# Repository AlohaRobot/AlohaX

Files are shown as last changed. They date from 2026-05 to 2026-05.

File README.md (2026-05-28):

AlohaX_缩小

# AlohaX Project

Dual-arm mobile robot project based on ROS2 Humble.

## Project Overview

AlohaX is a dual-arm robot system with the following features:
- **Dual-arm system**: Left and right 6-DOF arms (SOARM101)
- **Mobile base**: Dual drive wheel platform
- **Vertical lift**: Additional lift DOF (ID 11)

## Project Structure

```
alohax_ws/
├── src/
│   ├── alohax_urdf/              # URDF robot model and mesh files
│   ├── alohax_hw_bridge/         # Hardware bridge (core)
│   ├── alohax_moveit_config/     # MoveIt motion planning config
│   ├── alohax_bringup/           # Launch scripts
├── docs/                         # Project documentation
│   ├── AlohaX_Robot_Introduction.md
│   ├── AlohaX_BOM.md
│   ├── AlohaX_Assembly_Guide.md
│   ├── Serial_Port_Fix_Method.md
│   └── media/                    # Documentation images
├── examples/                     # Example programs
│   ├── debug/                    # Debug tools
│   │   ├── motors.py             # Motor control debug
│   │   ├── axis.py               # Lift axis control
│   │   ├── wheels.py             # Base control
│   │   ├── README_debug.md       # Debug tool usage guide
│   │   ├── action_scripts/       # Action scripts
│   │   │   ├── go_to_restposition.txt
│   │   │   ├── go_to_midpoint.txt
│   │   │   └── test_dance.txt
│   │   ├── test_cv.py            # Computer vision test
│   │   ├── test_mic.py           # Microphone test
│   │   ├── test_cuda.py          # CUDA test
│   │   ├── test_network.py       # Network test
│   │   ├── test_dataset.py       # Dataset test
│   │   └── test_input.py         # Input test
│   └── tele/                     # Teleoperation programs
│       ├── alohax_xbox.py        # Xbox controller
│       ├── alohax_keyboard.py    # Keyboard control
│       ├── alohax_joycon.py      # Joycon control (recommended)
│       ├── wheels_joycon.py      # Joycon base control
│       └── AlohaX_Joycon_Software_Design.md  # Joycon control detailed design
├── build/                        # Build output
├── install/                      # Install output
└── log/                          # Log output
```

## Hardware Configuration

### Motor Bus Configuration

**Bus1** (`/dev/so101_L`):
- ID 1-6: Left arm joints
- ID 7-8: Drive wheels (velocity mode)
- ID 11: Vertical lift

**Bus2** (`/dev/so101_R`):
- ID 1-6: Right arm joints

### Joint Configuration

Robot includes the following joints:

**Left arm (6 DOF)**:
- `left_arm_shoulder_pan`: Shoulder pan
- `left_arm_shoulder_lift`: Shoulder lift
- `left_arm_elbow_flex`: Elbow flex
- `left_arm_wrist_flex`: Wrist flex
- `left_arm_wrist_roll`: Wrist roll
- `left_arm_gripper`: Gripper

**Right arm (6 DOF)**:
- `right_arm_shoulder_pan`: Shoulder pan
- `right_arm_shoulder_lift`: Shoulder lift
- `right_arm_elbow_flex`: Elbow flex
- `right_arm_wrist_flex`: Wrist flex
- `right_arm_wrist_roll`: Wrist roll
- `right_arm_gripper`: Gripper

**Base**:
- `base_left_wheel`: Left drive wheel
- `base_right_wheel`: Right drive wheel

**Lift**:
- `vertical_lift`: Vertical lift DOF

## Quick Start

### Environment Requirements

- ROS2 Humble
- Python 3.10+
- Feetech servo drivers

### Build Project

```bash
cd /home/wolf/alohax_ws
colcon build --symlink-install
source install/setup.bash
```
```bash
cd /home/seeed/alohax_ws
colcon build --symlink-install
source install/setup.bash
```

### Launch Robot

#### 1. Visualize model (without hardware connection)

```bash
ros2 launch alohax_urdf display.launch.py
```

#### 2. Full launch (real hardware)

```bash
ros2 launch alohax_bringup alohax.launch.py
```

#### 3. Specify serial ports

```bash
ros2 launch alohax_bringup alohax.launch.py \
  port1:=/dev/ttyACM0 \
  port2:=/dev/ttyACM1
```

#### 4. Visualize only (without hardware)

```bash
ros2 launch alohax_bringup alohax.launch.py hardware:=false
```

#### 5. Launch parameter description

`alohax.launch.py` supports the following optional parameters:

| Parameter | Default | Description |
|---|---|---|
| `hardware` | `true` | Whether to connect real hardware |
| `gui` | `false` | Whether to start joint_state_publisher_gui |
| `moveit` | `true` | Whether to start MoveIt |
| `port1` | `/dev/so101_L` | Left serial port |
| `port2` | `/dev/so101_R` | Right serial port |
| `calib_file` | `alohax_calibration.yaml` | Calibration file path |
| `publish_hz` | `50.0` | Joint state publish rate (Hz) |
| `lift_travel_m` | `0.25` | Lift travel (meters) |
| `lift_motor_degrees_per_meter` | `144000.0` | Lift motor degrees per meter |
| `rviz` | `true` | Whether to start RViz2 |

### Launch MoveIt Motion Planning

```bash
ros2 launch alohax_moveit_config move_group.launch.py
```

## Controller Configuration

Project has the following controllers configured:
- `both_arms_controller`: Dual-arm combined control (includes vertical_lift)
- `left_arm_controller`: Left arm independent control (includes vertical_lift)
- `right_arm_controller`: Right arm independent control
- `left_gripper_controller`: Left gripper control
- `right_gripper_controller`: Right gripper control
- `joint_state_broadcaster`: Joint state broadcaster

Config file locations:
- [alohax_controllers.yaml](src/alohax_hw_bridge/config/alohax_controllers.yaml)
- [alohax_calibration.yaml](src/alohax_hw_bridge/config/alohax_calibration.yaml)

## Calibration and Tuning

### Calibration File

Calibration file is at `src/alohax_hw_bridge/config/alohax_calibration.yaml`, contains:
- `homing_offset`: Zero offset
- `range_min`: Minimum position
- `range_max`: Maximum position

### Adjust Calibration Parameters

Adjust parameters in calibration file based on actual hardware:

```yaml
left_arm_shoulder_pan:
  homing_offset: 2084
  range_min: 745
  range_max: 3424
```

## Troubleshooting

### Common Issues

**1. Hardware connection failed**

```bash
# Check serial ports
ls -l /dev/so101_L /dev/so101_R

# Check permissions
sudo chmod 666 /dev/so101_L /dev/so101_R
```

**2. MoveIt Action server not found**

```bash
# Ensure MoveIt is started
ros2 launch alohax_bringup xlerobot.launch.py moveit:=true

# Check Action servers
ros2 action list | grep move
```

**3. Planning failed**

- Check if target position exceeds joint limits
- Increase planning time (modify `PLANNING_TIME`)
- Check if starting state matches actual

## Future Work Recommendations

1. **Improve URDF model**: Add more precise link dimensions, inertia parameters, and collision models
2. **Import meshes**: Place STL/DAE models in `meshes` directory
3. **Calibration tuning**: Adjust calibration file parameters based on actual hardware
4. **Safety limits**: Adjust joint limits based on actual arm mounting position
5. **Testing verification**: Gradually test each joint motion and base drive

## Example Programs

Project includes rich example programs in `examples/` directory:

### Debug Tools (`debug/`)
Provides low-level hardware debugging, direct motor control without ROS:
- `motors.py`: Motor state viewing, single motor control, ID configuration, phase tuning, homing, script execution
- `axis.py`: Vertical lift axis independent control
- `wheels.py`: Base wheel independent control (WSAD/arrow keys)
- `action_scripts/`: Predefined action scripts (homing, midpoint, dance)
- Test scripts: `test_cv.py`, `test_mic.py`, `test_cuda.py`, `test_network.py`, etc.

See [examples/debug/README_debug.md](examples/debug/README_debug.md) for detailed usage.

### Teleoperation Programs (`tele/`)
Provides multiple controller direct control modes (skip ROS bridge):

| Program | Device | Description |
|---|---|---|
| `alohax_joycon.py` | Joycon | **Recommended**, dual Joycon control left/right arms, base, lift, with real-time status, current monitoring, 4 speed levels, timeout protection |
| `alohax_xbox.py` | Xbox controller | Xbox controller support |
| `alohax_keyboard.py` | Keyboard | Keyboard control |
| `wheels_joycon.py` | Joycon | Simplified, base only |

See [examples/tele/AlohaX_Joycon_Software_Design.md](examples/tele/AlohaX_Joycon_Software_Design.md) for Joycon control detailed design.

### Quick Start Joycon Control
```bash
python3 examples/tele/alohax_joycon.py
```

## Documentation

Project documentation is in `docs/` directory:
- [AlohaX_Robot_Introduction.md](docs/AlohaX_Robot_Introduction.md): Project overview
- [AlohaX_BOM.md](docs/AlohaX_BOM.md): Detailed bill of materials
- [AlohaX_Assembly_Guide.md](docs/AlohaX_Assembly_Guide.md): Complete assembly guide (with images)
- [Serial_Port_Fix_Method.md](docs/Serial_Port_Fix_Method.md): Serial port fix method

## Dependencies

- ROS2 Humble
- MoveIt2
- joint_state_publisher
- joint_state_publisher_gui
- robot_state_publisher
- rviz2
- xacro
- Feetech servo drivers

## License

Apache-2.0

## Maintainer

Wang Feng (wf270@163.com)

AlohaX卡通形象
AlohaX3

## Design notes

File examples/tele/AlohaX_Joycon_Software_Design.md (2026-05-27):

# AlohaX Joycon Teleoperation Software Design

## 1. Overview

This software is AlohaX hardware's Joycon controller direct control program, uses direct hardware control mode (skip ROS bridge), controls left and right arms, base movement, and vertical lift mechanism through two Joycons.

**Main Features**:
- Dual Joycon control (left/right)
- Direct Feetech motor communication
- Real-time status display (including current, load monitoring)
- Configurable speed levels (4 levels, base/arm/lift independent parameters)
- Lift mechanism calibration function
- Joycon timeout protection (auto unload torque)
- Global homing function (Capture button)
- Torque enable/disable toggle (Home button)

---

## 2. Hardware Configuration

### 2.1 Motor Bus Configuration

#### Bus1 (Left bus /dev/so101_L)
| Motor Name | ID | Model | Normalization Mode |
|---|----|---|---|
| left_arm_shoulder_pan | 1 | sts3215 | DEGREES |
| left_arm_shoulder_lift | 2 | sts3215 | DEGREES |
| left_arm_elbow_flex | 3 | sts3215 | DEGREES |
| left_arm_wrist_flex | 4 | sts3215 | DEGREES |
| left_arm_wrist_roll | 5 | sts3215 | DEGREES |
| left_arm_gripper | 6 | sts3215 | RANGE_0_100 |
| base_left_wheel | 7 | sts3215 | RANGE_0_100 |
| base_right_wheel | 8 | sts3215 | RANGE_0_100 |
| vertical_lift | 11 | sts3215 | DEGREES |

#### Bus2 (Right bus /dev/so101_R)
| Motor Name | ID | Model | Normalization Mode |
|---|----|---|---|
| right_arm_shoulder_pan | 1 | sts3215 | DEGREES |
| right_arm_shoulder_lift | 2 | sts3215 | DEGREES |
| right_arm_elbow_flex | 3 | sts3215 | DEGREES |
| right_arm_wrist_flex | 4 | sts3215 | DEGREES |
| right_arm_wrist_roll | 5 | sts3215 | DEGREES |
| right_arm_gripper | 6 | sts3215 | RANGE_0_100 |

### 2.2 Motor Groups
- **Left arm joints**: left_arm_*
- **Right arm joints**: right_arm_*
- **Base wheels**: base_* (left/right wheel direction sign `BASE_WHEEL_SIGN`: left=-1.0, right=1.0)
- **Lift joint**: vertical_lift (direction sign `LIFT_DIRECTION_SIGN = -1.0`)

---

## 3. Parameter Configuration

### 3.1 Mechanical Parameters
| Parameter Name | Value | Description |
|---|---|---|
| STEPS_PER_DEG | 4096/360 | Steps per degree |
| WHEEL_RADIUS | 0.05 | Wheel radius (meters) |
| WHEEL_BASE | 0.30 | Wheel base (meters) |
| LIFT_TRAVEL_M | 0.25 | Lift travel (meters) |
| LIFT_MOTOR_DEGREES_PER_METER | 144000 | Lift motor degrees per meter |
| JOYCON_FRAME_TIMEOUT_SEC | 2.0 | Joycon timeout threshold (seconds) |
| JOYCON_RECONNECT_INTERVAL_SEC | 1.0 | Joycon reconnect interval (seconds) |

### 3.2 Speed Level System

Code defines **three independent speed level sets**, 4 levels each, synchronized switching.

#### Base Speed Levels (BASE_SPEED_LEVELS)
| Level | Linear Speed (m/s) lin | Angular Speed (deg/s) ang |
|---|---|---|
| 1 | 0.05 | 20.0 |
| 2 | 0.10 | 40.0 |
| 3 | 0.15 | 70.0 |
| 4 | 0.50 | 572.0 |

#### Arm Speed Levels (ARM_SPEED_LEVELS)
| Level | P Coeff | I Coeff | D Coeff | Acceleration acc | Step (degrees) |
|---|---|---|---|---|---|
| 1 | 4 | 0 | 11 | 64 | 0.025 |
| 2 | 8 | 0 | 22 | 128 | 0.05 |
| 3 | 12 | 0 | 32 | 192 | 0.075 |
| 4 | 16 | 0 | 43 | 254 | 0.1 |

#### Lift Mechanism Speed Levels (LIFT_SPEED_LEVELS)
| Level | kp_vel Velocity Proportional Gain | v_max Max Velocity | step Step (mm) |
|---|---|---|---|
| 1 | 75 | 325 | 0.5 |
| 2 | 150 | 650 | 1.0 |
| 3 | 225 | 975 | 1.5 |
| 4 | 300 | 1300 | 2.0 |

**Note**: During homing operation, speed level automatically drops to `max(1, (normal_level+1)//2)`, restores original level after completion.

### 3.3 Joint Limits (radians)
| Joint | Min | Max |
|---|-----|-----|
| shoulder_pan | -1.996 | 2.111 |
| shoulder_lift | -2.004 | 2.028 |
| elbow_flex | -0.072 | 2.995 |
| wrist_flex | -2.238 | 1.334 |
| wrist_roll | -3.139 | 3.140 |
| gripper | 0.002 | 2.069 |

### 3.4 Calibration Parameters (CALIBRATION)

All motors have independent zero_position (Present_Position raw value at home pose):

| Motor Name | zero_position |
|---|---|
| left_arm_shoulder_pan | 2047 |
| left_arm_shoulder_lift | 2047 |
| left_arm_elbow_flex | 2047 |
| left_arm_wrist_flex | 2047 |
| left_arm_wrist_roll | 1000 |
| left_arm_gripper | 2048 |
| right_arm_shoulder_pan | 2047 |
| right_arm_shoulder_lift | 2047 |
| right_arm_elbow_flex | 2047 |
| right_arm_wrist_flex | 2047 |
| right_arm_wrist_roll | 1000 |
| right_arm_gripper | 2048 |
| vertical_lift | 2000 |

**Note**: Gripper conversion uses hardcoded range_min=2048 / range_max=3396 (hardcoded in `joint_position_to_motor_cmd` / `motor_cmd_to_joint_position`, not in CALIBRATION dictionary).

### 3.5 PID Control Parameters (Dynamically Adjustable)

PID parameters switch with speed level, see section 3.2 arm speed level table. Level 4 (highest speed): P=16, I=0, D=43, Acc=254. Gripper does not set PID parameters.

### 3.6 Lift Mechanism Parameters

| Parameter Name | Value | Description |
|---|---|---|
| min_height_mm | -450 | Minimum height (millimeters) |
| max_height_mm | 50 | Maximum height (millimeters) |
| descent_floor_mm | -445 | Descent limit (millimeters) |
| kp_vel | Dynamic | Velocity proportional gain (changes with level) |
| v_max | Dynamic | Max velocity (changes with level) |
| on_target_mm | 1.0 | Target threshold (millimeters) |
| step_mm | Dynamic | Step value (changes with level) |
| _ticks_per_rev | 4096 | Encoder ticks per revolution |
| _mm_per_deg | 84/360 | Millimeters per degree |

---

## 4. Main Loop Cycle and Servo Polling Cycle

### 4.1 Main Loop Cycle
```python
self.timer = self.create_timer(0.033, self.timer_callback)
```
- **Main loop cycle**: 33ms (approx 30Hz)
- **Timer callback function**: `timer_callback()`
- **Cycle monitoring**: `last_callback_time` records last callback time, real-time calculates actual cycle and displays

### 4.2 Servo Polling and Communication Cycle

#### Write Cycle
| Hardware Group | Communication Method | Cycle |
|---|---|---|
| Left arm joints | sync_write | 33ms |
| Right arm joints | sync_write | 33ms |
| Base wheels | sync_write | 33ms |
| Vertical lift | write | 33ms |

#### Read Cycle
Reading uses bulk register reading (`_sync_read_multi_registers`), reads Present_Position, Present_Velocity, Present_Load three consecutive registers (address 56-61, length 6 bytes) at once. Additionally reads Present_Current separately (address 69, not consecutive).

| Hardware Group | Communication Method | Cycle | Read Content |
|---|---|---|---|
| Left arm joints | sync_read | 33ms | Present_Position / Velocity / Load + Current |
| Right arm joints | sync_read | 33ms | Present_Position / Velocity / Load + Current |
| Vertical lift | sync_read | 33ms | Present_Position + Current + Load |
| Base wheels | sync_read | 33ms | Present_Position + Current + Load |

### 4.3 Communication Configuration
| Parameter Name | Value | Description |
|---|---|---|
| Return_Delay_Time | 0 | Return delay time (0μs) |
| Maximum_Acceleration | Dynamic | Maximum acceleration (changes with speed level) |
| Acceleration | Dynamic | Acceleration (changes with speed level) |
| Unloading_Condition | 0x2f | Unloading condition register |

---

## 5. Control Mapping

### 5.1 Button Mapping Constants

Code defines `LEFT_KEYMAP` and `RIGHT_KEYMAP` two dictionaries, maps physical buttons to control actions.

#### Left Joycon Button Mapping (LEFT_KEYMAP)
| Control Action | Physical Button |
|---|---|
| elbow_flex-, X- (stick_up) | Stick up |
| elbow_flex+, X+ (stick_down) | Stick down |
| wrist_roll+ (stick_right) | Stick right |
| wrist_roll- (stick_left) | Stick left |
| wrist_flex- (stick_pressed_up) | Press stick + up |
| wrist_flex+ (stick_pressed_down) | Press stick + down |
| shoulder_pan+ (l_right) | L/ZL + stick right |
| shoulder_pan- (l_left) | L/ZL + stick left |
| shoulder_lift- (l_up) | L/ZL + stick up |
| shoulder_lift+ (l_down) | L/ZL + stick down |
| gripper+ (zl) | ZL |
| vertical_lift+ (up) | Up button |
| vertical_lift- (down) | Down button |

#### Right Joycon Button Mapping (RIGHT_KEYMAP)
| Control Action | Physical Button |
|---|---|
| elbow_flex- (stick_up) | Stick up |
| elbow_flex+ (stick_down) | Stick down |
| wrist_roll+ (stick_right) | Stick right |
| wrist_roll- (stick_left) | Stick left |
| wrist_flex- (stick_pressed_up) | Press stick + up |
| wrist_flex+ (stick_pressed_down) | Press stick + down |
| shoulder_pan+ (r_right) | R/ZR + stick right |
| shoulder_pan- (r_left) | R/ZR + stick left |
| shoulder_lift- (r_up) | R/ZR + stick up |
| shoulder_lift+ (r_down) | R/ZR + stick down |
| gripper+ (zr) | ZR |

### 5.2 Control Function Summary

#### Right Joycon (Control Right Arm and Base)
| Operation | Function |
|---|---|
| Stick left/right | wrist_roll |
| Stick up/down | elbow_flex |
| Stick pressed + up/down | wrist_flex |
| R/ZR + stick left/right | shoulder_pan |
| R/ZR + stick up/down | shoulder_lift |
| ZR | Right gripper close |
| X | Forward |
| B | Backward |
| Y | Left turn |
| A | Right turn |
| Plus | Speed level +1 (max 4) |
| Home | Toggle torque enable/disable |

#### Left Joycon (Control Left Arm and Lift)
| Operation | Function |
|---|---|
| Stick left/right | wrist_roll |
| Stick up/down | elbow_flex |
| Stick pressed + up/down | wrist_flex |
| L/ZL + stick left/right | shoulder_pan |
| L/ZL + stick up/down | shoulder_lift |
| ZL | Left gripper close |
| Up | Lift up |
| Down | Lift down |
| Minus | Speed level -1 (min 1) |
| Capture | Global homing |

### 5.3 Shared Control
| Operation | Function |
|---|---|
| Right Plus | Speed level +1 (max 4) |
| Left Minus | Speed level -1 (min 1) |
| Right Home | Toggle torque enable/disable |
| Left Capture | Global homing |

---

## 6. Main Classes and Functions

### 6.1 TeleopDisplay Class
**Function**: curses-based real-time status display

**Added display content**:
- Each motor current (mA) and load value
- Vertical lift actual height
- Base left/right wheel status and current/load
- Main loop cycle (ms)
- Torque status (ON/OFF)
- Homing operation flag

**Main methods**:
- `init_curses()`: Initialize curses display (including color pairs)
- `cleanup()`: Cleanup display resources
- `update_left_arm(state)`: Update left arm target position
- `update_right_arm(state)`: Update right arm target position
- `update_lift(state)`: Update lift target position (meters)
- `update_lift_hw(state)`: Update lift actual position (meters)
- `update_base(state)`: Update base status
- `update_grippers(left, right)`: Update gripper status
- `update_hw_arm_states(left, right)`: Update hardware joint positions
- `update_arm_motor_states(...)`: Update all motors current, load
- `update_lift_motor_states(current, load)`: Update lift current and load
- `update_wheel_states(...)`: Update base left/right wheel speed, position, current, load
- `update_torque_status(enabled)`: Update torque status
- `update_base_speed_level(level)`: Update current speed level
- `update_loop_period(ms)`: Update main loop cycle
- `set_reset_flag(flag)`: Set homing flag
- `display()`: Refresh display

### 6.2 SimpleTeleopArm Class
**Function**: Arm joint control

**Constructor**: `__init__(prefix="left", kp=1, speed_level=2)`
- `prefix`: left or right
- `speed_level`: Initial speed level (default 2)

**Main methods**:
- `move_to_zero_position()`: Return to zero position
- `handle_keys(key_state)`: Handle key input to update target position (including JOINT_LIMITS clamping)
- `_update_step()`: Update degree_step based on current speed level
- `update_speed_level(level)`: Update speed level and call `_update_step()`

**Member variables**:
- `degree_step`: Degree increment per step (radians, changes with speed level: 0.025~0.1 degrees)
- `target_positions`: Target position dictionary (radians)
- `zero_pos`: Zero position (all zeros)
- `speed_level`: Current speed level

### 6.3 ContinuousLiftControl Class
**Function**: Vertical lift mechanism continuous control (supports multi-turn continuous rotation)

**Constructor**: `__init__(speed_level=2)`

**Main methods**:
- `configure(bus, motor_name)`: Configure hardware, read initial encoder value
- `home(use_current=True)`: Homing calibration (push up stall → descend 50mm → set zero)
- `set_height_mm(target_mm)`: Set target height (clamped [-450, 50] mm)
- `compute_velocity()`: Calculate velocity command (PID velocity loop, including limit protection)
- `get_height_mm()`: Get current height
- `move_to_zero_position()`: Return to zero position (target_height_mm = 0)
- `handle_keys(key_state)`: Handle key input (Up/Down buttons)
- `_update_extended_ticks()`: Update accumulated turns (handle multi-turn winding)
- `_update_params()`: Update kp_vel/v_max/step_mm based on current speed level
- `update_speed_level(level)`: Update speed level and call `_update_params()`

**Member variables**:
- `_ticks_per_rev` / `_deg_per_tick` / `_mm_per_deg`: Internal parameters
- `min_height_mm` / `max_height_mm` / `descent_floor_mm`: Limits
- `kp_vel` / `v_max` / `step_mm` / `on_target_mm`: Control parameters (changes with speed level)
- `dir_sign = -1.0`: Direction sign

### 6.4 FixedAxesJoyconRobotics Class
**Function**: Joycon input handling (inherits from JoyconRobotics)

**Added features**:
- Input frame timeout detection: Mark latest frame time through register_update_hook
- `seconds_since_last_input_frame()`: Seconds since last input frame
- `is_input_frame_timed_out(timeout=2.0)`: Whether timed out

**Main overrides**:
- `__init__(device)`: Configure stick zero, register input frame hook
- `get_stick_values()`: Get stick values
- `reset_joycon()`: Reset (silent version, reduces wait time)
- `common_update()`: Update (remove auto-reset logic)

**Stick zero configuration**:
- Right Joycon: Vertical=1900, Horizontal=2100
- Left Joycon: Vertical=2300, Horizontal=2000

### 6.5 AlohaXTeleopNode Class
**Function**: Main control node (ROS2 Node)

**Added core features**:
- **Joycon timeout protection**: Input frame timeout 2s → stop base → freeze lift → clear target positions → unload dual arm torque
- **Global homing**: Capture button triggers, all joints return to zero position, uses half speed
- **Torque toggle**: Home button toggles torque enable/disable
- **Dynamic PID**: Real-time update motor PID / acceleration parameters when speed level switches

**Main methods**:
- `__init__(port1, port2, display)`: Initialize (connect hardware, configure motors, create timer)
- `_connect_hardware()`: Connect Bus1/Bus2, scan motors, configure, initialize home position
- `_configure_bus(bus, active_motors, is_bus1)`: Configure single bus motor parameters (mode, PID, acceleration, unloading condition)
- `_init_cmd_to_home()`: Initialize all motor commands to home position
- `_update_motor_speed_params()`: Update all motor PID / acceleration based on speed level
- `_update_motor_homing_speed_params()`: Set homing speed (approx half of level)
- `_check_homing_complete()`: Detect if homing complete (within 1 degree as arrived)
- `_write_commands()`: Write motor commands (sync_write Goal_Position + Goal_Velocity)
- `_read_hardware_states()`: Read hardware states (bulk register read Present_Position/Velocity/Load + Present_Current)
- `_sync_read_multi_registers()`: Bulk read consecutive registers
- `_is_joycon_fresh(joycon)`: Check if Joycon is not timed out
- `_set_base_cmd_zero()`: Clear base command
- `_freeze_lift_target()`: Freeze lift target height
- `_clear_all_targets()`: Clear all target values (timeout recovery anti-shock)
- `_disable_arm_torque()` / `_enable_arm_torque()`: Unload/enable torque
- `_update_joycon_watchdogs()`: Update Joycon watchdogs
- `_update_timeout_display(states)`: Update timeout display
- `timer_callback()`: Main loop callback (including timeout detection, homing, speed control, Joycon handling, hardware communication, display update)
- `cleanup(keep_display=True)`: Cleanup resources

**Key members**:
- `bus1` / `bus2`: FeetechMotorsBus instances
- `bus1_connected` / `bus2_connected`: Bus connection status
- `active_bus1` / `active_bus2`: Scanned active motor list
- `left_arm` / `right_arm`: SimpleTeleopArm instances
- `lift`: ContinuousLiftControl instance
- `joycon_right` / `joycon_left`: FixedAxesJoyconRobotics instances
- `cmd`: Motor command dictionary
- `display`: TeleopDisplay instance
- `torque_enabled`: Torque enable status
- `base_speed_level`: Current speed level (1-4)
- `is_homing`: Whether currently homing
- `normal_speed_level`: Normal working speed level
- `_joycon_timeout_state`: Joycon timeout state dictionary
- `_lift_frozen_height`: Lift height frozen at timeout

### 6.6 Helper Functions

| Function Name | Function |
|---|---|
| `_patch_joycon_open()` | Fix Joycon Bluetooth connection (open hid device through path) |
| `_joycon_reconnect(self)` | Joycon reconnect logic |
| `_safe_update_input_report(self)` | Safe update input report (exception handling) |
| `degps_to_raw(degps)` | Degrees/second to raw velocity value (including sign bit handling) |
| `body_to_wheel_raw(v_cmd, omega_cmd_degps)` | Body velocity to wheel raw velocity |
| `degrees_to_raw(name, degrees)` | Degrees to raw position value (including calibration offset) |
| `raw_to_degrees(name, raw)` | Raw position value to degrees (including calibration offset) |
| `joint_position_to_motor_cmd(name, position)` | Joint position (radians/meters) to motor command |
| `motor_cmd_to_joint_position(name, cmd)` | Motor command to joint position |
| `clamp(value, min_val, max_val)` | Value clamping utility |
| `get_joycon_key_state(joycon, keymap)` | Get Joycon key state based on keymap |
| `get_base_action(joycon, speed_level)` | Get base action (forward/backward/left turn/right turn) |
| `parse_args()` | Parse command line arguments |
| `run_lift_calibration(port1)` | Run lift calibration |
| `main(args)` | Main function |

---

## 7. Workflow

### 7.1 Startup Flow
```
main()
  ├─ Parse command line arguments (parse_args)
  ├─ Lift mechanism calibration (optional, interactive prompt)
  │   └─ run_lift_calibration(port1)
  ├─ Initialize ROS2 (rclpy.init)
  ├─ Connect Joycon (suppress output)
  │   ├─ FixedAxesJoyconRobotics("right")
  │   ├─ FixedAxesJoyconRobotics("left")
  │   └─ Check if Joycon connected
  ├─ Create AlohaXTeleopNode
  │   ├─ Hardware connection (_connect_hardware)
  │   │   ├─ Connect Bus1/Bus2
  │   │   ├─ Scan motors (broadcast_ping)
  │   │   ├─ Configure motors (mode, PID, acceleration, unloading condition)
  │   │   ├─ Initialize to home position
  │   │   └─ Configure lift mechanism (lift.configure)
  │   └─ Create timer (33ms)
  ├─ Pass Joycon to node
  ├─ Initialize display (TeleopDisplay + curses)
  └─ rclpy.spin(node) enter loop
```

### 7.2 Main Loop Flow (timer_callback)
```
33ms cycle execution:
  ├─ Calculate loop cycle (display real-time ms)
  ├─ Update Joycon watchdogs (_update_joycon_watchdogs)
  │
  ├─ Home/Capture button detection
  │   ├─ Home → Toggle torque enable/disable
  │   ├─ Capture → Trigger global homing (is_homing=true)
  │   │   └─ Save normal speed, switch to homing speed (half)
  │   └─ Homing → Detect complete (within 1 degree), restore normal speed after completion
  │
  ├─ Plus/Minus button detection → Speed level adjustment
  │   └─ _update_motor_speed_params() Update PID/acceleration
  │
  ├─ Joycon timeout judgment
  │   ├─ If timed out → Stop base → Freeze lift → Clear targets → Unload torque
  │   └─ If recovered → Re-enable torque
  │
  ├─ Normal control (Joycon not timed out)
  │   ├─ Left Joycon handling
  │   │   ├─ get_joycon_key_state(LEFT_KEYMAP)
  │   │   ├─ Update left arm target position
  │   │   ├─ Update lift target position
  │   │   └─ Update cmd dictionary
  │   └─ Right Joycon handling
  │       ├─ get_joycon_key_state(RIGHT_KEYMAP)
  │       ├─ Update right arm target position
  │       ├─ Get base velocity command
  │       └─ Update cmd dictionary
  │
  ├─ Write hardware (_write_commands)
  │   ├─ Left arm: sync_write Goal_Position (degrees to raw value)
  │   ├─ Base: sync_write Goal_Velocity (including direction sign)
  │   ├─ Lift: write Goal_Velocity (PID velocity loop calculation)
  │   └─ Right arm: sync_write Goal_Position (degrees to raw value)
  │
  ├─ Read hardware states (_read_hardware_states)
  │   ├─ Left arm: bulk read Present_Position/Velocity/Load + Current
  │   ├─ Lift: sync_read Present_Position/Current/Load
  │   ├─ Base: sync_read Present_Position/Current/Load
  │   └─ Right arm: bulk read Present_Position/Velocity/Load + Current
  │
  └─ Update display
      ├─ Target position (left/right arms, lift, gripper)
      ├─ Hardware position (left/right arms, lift, base)
      ├─ Motor states (current, load)
      ├─ Loop cycle, speed level, torque status, homing flag
      └─ display() Refresh
```

### 7.3 Lift Calibration Flow
```
run_lift_calibration(port1)
  ├─ Connect Bus1 (only includes lift motor)
  ├─ Find lift motor (ID=11)
  ├─ Create ContinuousLiftControl instance
  ├─ Call home(use_current=True)
  │   ├─ Enable torque, lock motor
  │   ├─ Move up (Goal_Velocity=-1000)
  │   ├─ Loop detection (max 300s)
  │   │   ├─ Detect if current ≥ 450mA (stall)
  │   │   └─ Or detect if position no longer moves
  │   ├─ Stop
  │   ├─ Move down 50mm (retract)
  │   ├─ Wait for stable
  │   └─ Set as zero (z0_deg)
  └─ Disconnect
```

---

## 8. Motor Mode Configuration

| Motor Type | Operating_Mode | Description |
|---|---|---|
| Arm joints | POSITION | Position control mode |
| Base wheels | VELOCITY | Velocity control mode |
| Lift mechanism | VELOCITY | Velocity control mode (multi-turn continuous) |

**Note**: Gripper does not set PID parameters, only sets position command.

---

## 9. Command Line Arguments

| Argument | Default | Description |
|---|---|---|
| `--port1` | /dev/so101_L | Left bus serial port |
| `--port2` | /dev/so101_R | Right bus serial port |
| `--no-display` | - | Disable curses display (degrade to simple text output) |
| `--no-calibrate` | - | Skip lift calibration interactive prompt |

**Interactive behavior**: If not passing `--no-calibrate`, will prompt `Do you want to run lift calibration? (y/N)` at startup.

---

## 10. File Structure

```
alohax_joycon.py
├── Imports and patches (hid, joycon_core, `_patch_joycon_open`)
├── Hardware configuration (BUS1_MOTORS, BUS2_MOTORS, motor groups)
├── Speed level configuration (BASE_SPEED_LEVELS, ARM_SPEED_LEVELS, LIFT_SPEED_LEVELS)
├── Calibration parameters (CALIBRATION, each motor independent zero_position)
├── Motor conversion functions (degps_to_raw, degrees_to_raw, joint_position_to_motor_cmd, etc.)
├── clamp utility function
├── Button mapping configuration (LEFT_KEYMAP, RIGHT_KEYMAP)
├── Joint limit configuration (JOINT_LIMITS)
├── TeleopDisplay class
├── SimpleTeleopArm class
├── ContinuousLiftControl class
├── FixedAxesJoyconRobotics class
├── Button/base helper functions (get_joycon_key_state, get_base_action)
├── AlohaXTeleopNode class (main control node)
├── Lift calibration function (run_lift_calibration)
└── Main functions (parse_args, main)
```

---

## 11. Notes

1. **Unit Convention**:
   - Joint target position: radians (internal calculation)
   - Motor command: degrees (after conversion) / raw encoder value (gripper, lift)
   - Gripper: radians ↔ raw range 2048~3396 linear mapping
   - Raw position: encoder value (0-4095)

2. **Joycon Pairing**: Need to first pair Joycon through Bluetooth. Pairing info can be viewed through `bluetoothctl devices`.

3. **Joycon Connection Patch**: `_patch_joycon_open()` modifies Joycon library's `_open()` method, prioritizes opening through device path obtained from `hid.enumerate()`, solves issue where directly opening through VID/PID fails on some systems.

4. **Timeout Protection**: If Joycon has no input frame for 2 seconds, automatically unload torque and stop all motion.

5. **Calibration**: Recommend running lift calibration after first use or replacing mechanical structure.

6. **Display**: Requires terminal window at least 120x30 characters. If curses initialization fails, automatically degrades to `--no-display` mode.

7. **Homing**:
   - Capture button triggers global homing (all joints return to 0 position)
   - Homing speed approx half of current level speed
   - Homing timeout 10 seconds
   - Automatically restore original speed level after homing complete

8. **Exception Handling**: All exceptions in main loop are caught, ensures program does not exit due to single error. Base stops when error occurs.

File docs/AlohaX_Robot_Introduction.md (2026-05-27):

# AlohaX Robot Introduction

AlohaX is a dual-arm four-wheel humanoid robot that combines the core advantages of AlohaMini and XLeRobot. It is also currently one of the most cost-effective dual-arm four-wheel humanoid robots, focusing on practical applications in education and research scenarios.

https://github.com/liyiteng/AlohaMini
https://github.com/Vector-Wangel/XLeRobot

## Core Positioning

A low-cost practical dual-arm wheeled robot for education and research fields, capable of completing basic tasks such as picking up and transporting small items. Compared to traditional desktop teaching robots, it is cheaper and more practical. Compared to AlohaMini, it has higher stability, and compared to xlerobot, it has a wider working range.

## Core Design

### Base Solution
Adopts xlerobot0.4.0 core architecture (2 driving wheels + 2 driven wheels), optimal cost-effectiveness and stability. Alternatively, xlerobot0.3.0 or mecanum wheel solution can be selected (3-wheel version has better software compatibility with AlohaMini, supports left-right translation, but slower speed, weaker obstacle crossing ability, requires flat ground).
- IKEA Raskog cart retains only the bottom basket, base rotated 90 degrees, more coordinated aspect ratio, improved passability.
- Base basket reinforced with wood board, solves base softness and motion wobble issues.
- Arms naturally hang outside the body at zero position, more natural posture.

### Body and Dual Arms
Based on AlohaMini body module, key optimizations:
- Body module placed at front of base, convenient for picking up items.
- Arm mounting position lowered below shoulders, lower center of gravity, more natural posture.
- Retains AlohaMini body lift DOF, expands working range (covers ground to tabletop picking/transport scenarios).
- End maximum load 300g, can complete basic tasks such as picking up and transporting small items.

### Electronics and Wiring
- Main controller can choose NVIDIA Orin nano or Raspberry Pi series, or desktop PC or laptop.
- USB Hub placed above chest core module, power terminal below, reduces overall wiring length.
- Dual arm drivers/camera USB cables routed around shoulders, except for battery to power terminal cables, all other cables fixed to body core, aesthetic and tangle-free.
- Servo cables recommended to use twisted pairs, improves anti-interference, reduces packet loss and USB disconnection risks during operation (twisting method, terminal resistor configuration, software anti-interference optimization still in iteration).

## Power and Safety
- Power solution: 12V 20A lead-acid battery + dedicated switch case (safer, lower cost than lithium battery), battery placed at tail for counterweight, ensures center of gravity at robot center.
- Charging note: Only connect battery during operation, disconnect entire robot wiring during charging (most chargers output 14.6V, higher than maximum 12.6V input specified for Waveshare control board).
- Safety protection: Added DC circuit breaker, achieves overcurrent automatic power-off, also serves as emergency stop switch.
- Keep a safe distance during robot operation to prevent personal injury.
- Continuously monitor robot operation status during operation to prevent robot damage and fire hazards.

## Software Compatibility
Developed based on AlohaMini and xlerobot underlying architecture, retains compatibility with both robots' existing software ecosystems, reduces secondary development costs.

## Core Advantages
1. Cost: Price close to or lower than desktop teaching robots, one of the cheapest dual-arm four-wheel humanoid robots currently available.
2. Practicality: Can complete basic tasks such as picking up and transporting small items, suitable for education/research scenarios.
3. Stability: Larger base area, more stable motion, more natural arm posture.
4. Expandability: Retains body lift DOF, working range covers ground to tabletop.

## Acknowledgments
- Thanks to AlohaMini author liyiteng.
- Thanks to xlerobot author vector wang.

### Attachments
- [AlohaX_Assembly_Guide.md](AlohaX_Assembly_Guide.md)
- [AlohaX_BOM.md](AlohaX_BOM.md)

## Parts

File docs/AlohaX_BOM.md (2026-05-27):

# AlohaX Bill of Materials

AlohaX hardware includes mobile base and two slave arms. Arms directly reuse SO-ARM100/SO-ARM101 design. Therefore, if you already have two SO-ARM101 arms, you only need to assemble the mobile base. Communication between mobile base, arms, and main controller (can choose NVIDIA Orin nano, Raspberry Pi series, desktop PC or laptop) uses the same bus servo communication system.

*Note: Common tools such as bench vise, screwdriver set can be procured as needed, not listed in table below.*

## Mobile Base

| Item | Model / Description | Quantity | Unit Price (CN) | Purchase (CN) |
|---|---|---|---|---|
| Servo motor | Feetech / 12V 1/345 reduction ratio (STS3215-C018) | 4 | ¥110 | [Taobao](https://item.taobao.com/item.htm?id=996544351583) |
| Wheels | Driving wheel + driven wheel (xlerobot0.4.0 solution) | 2+2 | - | - |
| USB camera | 720p focal length 2.4mm, 36×36mm form factor | 3 | ¥125 | [Taobao](https://item.taobao.com/item.htm?id=666278411821) |
| 3D camera (optional) | Astra Pro | 1 | ¥180 | - |
| IKEA Raskog cart | Raskog cart | 1 | ¥199 | [IKEA](https://www.ikea.com/cn/zh/p/raskog-raskog-rollcontainer-gris-70386300/) |
| Battery | 12V 20A lead-acid battery | 1 | ¥158 | - |
| Battery switch cover | 12V 20A battery dedicated switch case | 1 | ¥70 | - |
| 6A DC circuit breaker | Overcurrent automatic power-off, also serves as emergency stop switch | 1 | 30 | - |
| USB Hub | 7-port | 1 | ¥70 | - |
| Wood board | For base reinforcement | 1 | - | - |
| Bearings | Select as needed | - | ¥3 | [Taobao](https://item.taobao.com/item.htm?id=565418362178) |
| M2×12 Phillips screws | For camera mounting | 12 | - | - |
| M3×12 hex socket screws | Select as needed | - | - | - |
| M3×18 hex socket screws | Select as needed | - | - | - |
| M2×30 hex socket screws | Select as needed | - | - | - |
| M3 hex nuts | Select as needed | - | - | - |
| M3×5×4 heat insert nuts | Select as needed | - | ¥5 | [Taobao](https://item.taobao.com/item.htm?id=809241671998) |
| M4×12 hex socket screws | Select as needed | - | - | - |
| M4×6×5 heat insert nuts | Select as needed | - | ¥4 | [Taobao](https://item.taobao.com/item.htm?id=809241671998) |
| Adhesive | Epoxy (highly recommended) / double-sided tape - for cable securing and structural bonding | 1 | ¥12 | [JD](https://item.jd.com/100141557259.html) |
| Servo extension cable | SCS 3-pin, 90cm | 2 | ¥3 | [Taobao](https://item.taobao.com/item.htm?id=616460581906) |
| SPL-62 terminal block | For power supply | 1 | ¥5 | [Taobao](https://item.taobao.com/item.htm?id=657816423504) |
| USB Type-C cable | Only for testing mobile base | 1 | ¥20 | [Tmall](https://detail.tmall.com/item.htm?id=754024805047) |
| Waveshare bus servo controller (or JUXI Bus Servo Adaptor) | Only for testing mobile base | 1 | ¥27 | [Tmall](https://detail.tmall.com/item.htm?id=738817173460) |
| 3D printed parts | PLA/PETG/ABS (files in project hardware directory) | - | - | - |

## Slave Arm

| Item | Model / Description | Quantity | Unit Price (CN) | Purchase (CN) |
|---|---|---|---|---|
| Servo motor | Feetech / 12V 1/345 reduction ratio (STS3215-C018) | 12 | ¥110 | [Taobao](https://item.taobao.com/item.htm?id=996544351583) |
| Waveshare bus servo controller | For connecting to main controller | 2 | ¥27 | [Tmall](https://detail.tmall.com/item.htm?id=738817173460) |
| USB camera | 720p focal length 3.8mm, 32×32mm form factor | 2 | ¥103 | [Taobao](https://item.taobao.com/item.htm?id=590682120464) |
| 1-to-2 DC splitter cable | 30cm, 5521 interface - for arm power supply | 1 | ¥5 | [Taobao](https://item.taobao.com/item.htm?id=594921965049) |
| DC extension cable | 1.5m, 5521 interface - for arm power supply | 2 | ¥2.50 | [Taobao](https://item.taobao.com/item.htm?id=43628177900) |
| USB Type-C cable | For connecting to main controller | 2 | ¥20 | [Tmall](https://detail.tmall.com/item.htm?id=754024805047) |
| 3D printed parts | PLA/PETG/ABS (files in project hardware directory) | 1 set | - | - |

## Main Controller (Optional)

| Item | Model / Description | Quantity | Unit Price (CN) | Purchase (CN) |
|---|---|---|---|---|
| Computing board | NVIDIA Orin nano / Raspberry Pi 5 (≥2GB RAM) / other SBC / PC | 1 | ¥600+ | [Taobao](https://item.taobao.com/item.htm?id=688878446695) |
| DC converter | 12V → 5V / 5A buck converter | 1 | ¥75 | [Taobao](https://item.taobao.com/item.htm?id=800698078303) |
| Display | 7-inch HD IPS HDMI interface + touch + Type C power (optional) | 1 | ¥291 | [Taobao](https://item.taobao.com/item.htm?id=592070943040) |

## Active Arm (Optional, for Teleoperation)

| Item | Model / Description | Quantity | Unit Price (CN) | Purchase (CN) |
|---|---|---|---|---|
| Servo motor | Feetech / 7.4V 1/147 reduction ratio (STS3215-C046) | 12 | ¥99 | [Taobao](https://item.taobao.com/item.htm?id=996544351583) |
| Waveshare bus servo controller | For connecting to PC | 2 | ¥27 | [Tmall](https://detail.tmall.com/item.htm?id=738817173460) |
| Battery | 5V lithium battery pack (5600mAh, DC 5521 interface) | 1 | ¥30 | [Taobao](https://item.taobao.com/item.htm?id=765749120668) |
| 1-to-2 DC splitter cable | 70cm - for arm power supply | 1 | ¥5 | [Taobao](https://item.taobao.com/item.htm?id=594921965049) |
| USB Type-C cable | For connecting to PC | 2 | ¥20 | [Tmall](https://detail.tmall.com/item.htm?id=754024805047) |
| 3D printed parts | PLA/PETG/ABS (files in project hardware directory) | 1 set | - | - |

> Note: Official SO-ARM100 design uses three different reduction ratios (1/147, 1/191, 1/345) for optimal performance. However, our testing shows that using a single reduction ratio (1/147) can provide excellent user experience and significantly simplify assembly. Table above reflects this simplified configuration.

## Main Component Summary

| Component | Model / Description | Quantity | Unit Price (CN) | Subtotal (CN) |
|---|---|---|---|---|
| Servo motor | Feetech STS3215 (12V bus) | 16 | ¥110 | ¥1,760 |
| Motor control board | Waveshare bus servo adapter | 3 | ¥27 | ¥81 |
| USB camera | 720p (3 base + 2 arms) | 5 | ¥111 | ¥555 |
| IKEA cart | Raskog cart | 1 | ¥199 | ¥199 |
| Battery + switch cover | 12V 20A lead-acid battery | 1 | ¥233 | ¥233 |
| 3D printing filament | PLA/PETG (approx 2kg) | 1 set | ¥250 | ¥250 |
| Other | - | 1 | ¥200 | ¥200 |
| **Total (excluding main controller and active arm)** | - | - | - | **¥3,278** |

> **Price Notes**:
> - Camera unit price average (base camera ¥125 + arm camera ¥103) / 5 = ¥111
> - Main controller (NVIDIA Orin nano/Raspberry Pi/PC) not included, can be selected as needed (¥600+)
> - Active arm (for teleoperation) not included, optional configuration
> - 3D printed parts and screws and other consumable prices not included, need to print or procure yourself

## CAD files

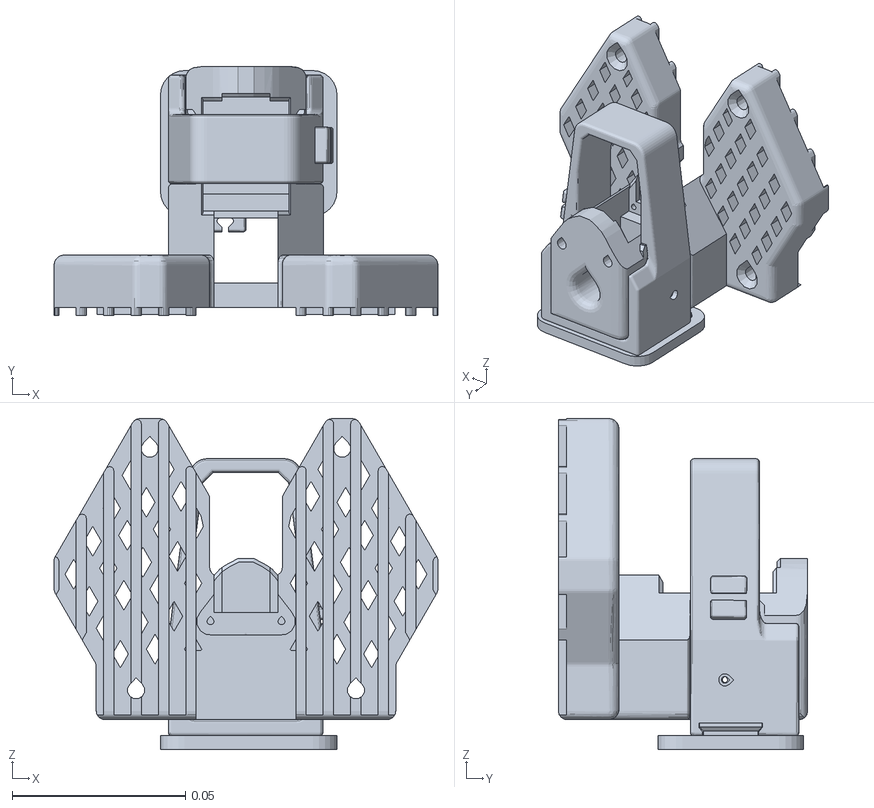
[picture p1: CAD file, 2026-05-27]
src/alohax_urdf/meshes/right_base.STL
0.111 x 0.072 x 0.0956

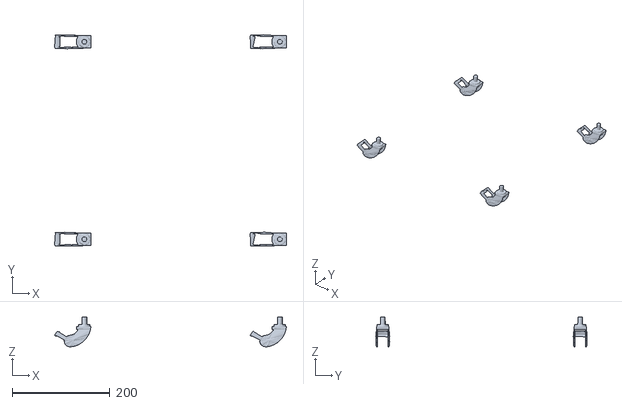
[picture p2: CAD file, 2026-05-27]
src/alohax_urdf/meshes/raskogwheel1.stl
474.6 x 432.7 x 61.2

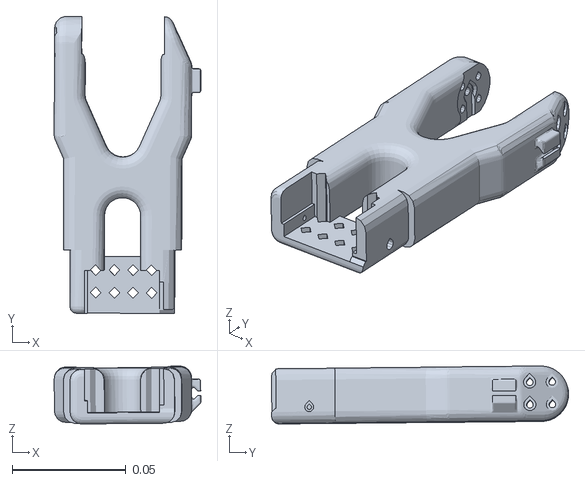
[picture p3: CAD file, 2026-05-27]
src/alohax_urdf/meshes/right_link3.STL
0.0646 x 0.131 x 0.0255

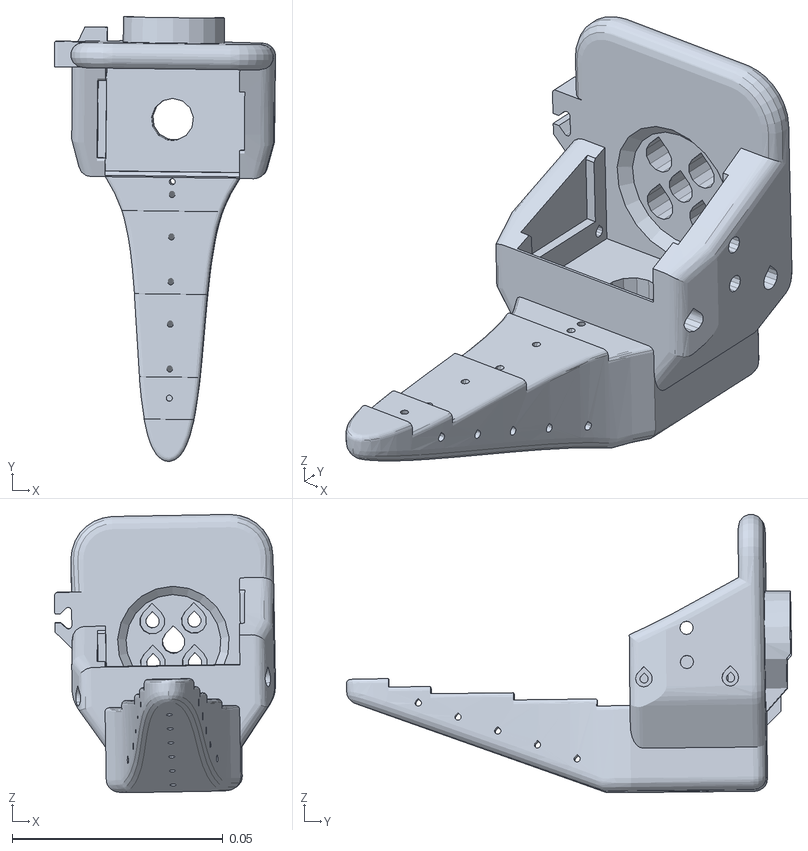
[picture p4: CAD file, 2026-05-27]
src/alohax_urdf/meshes/right_link5.STL
0.0524 x 0.105 x 0.066

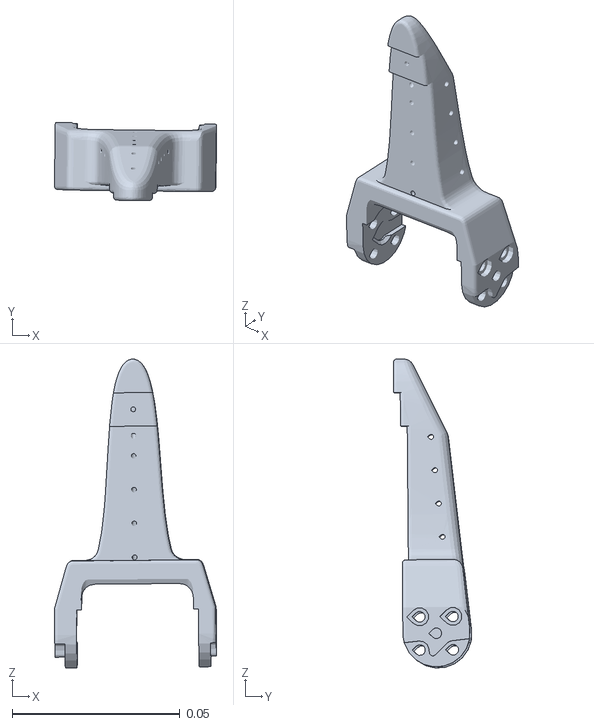
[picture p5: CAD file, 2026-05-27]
src/alohax_urdf/meshes/right_link6.STL
0.0483 x 0.0233 x 0.092

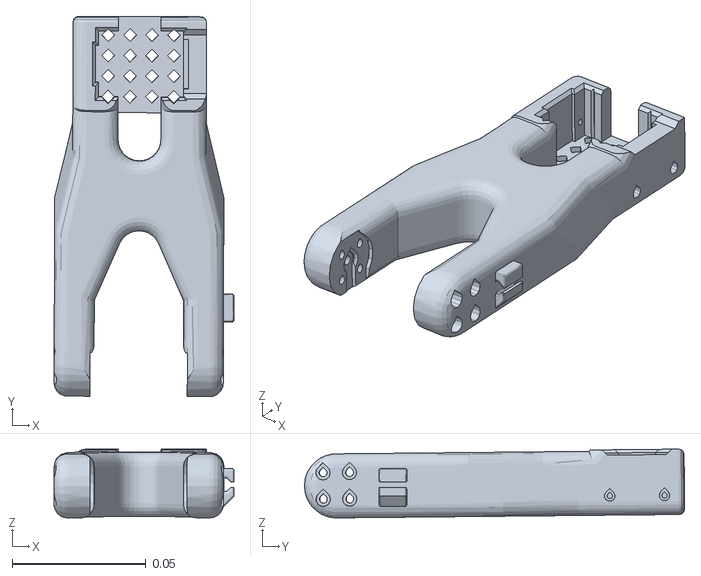
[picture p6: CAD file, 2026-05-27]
src/alohax_urdf/meshes/right_link2.STL
0.0674 x 0.142 x 0.0258

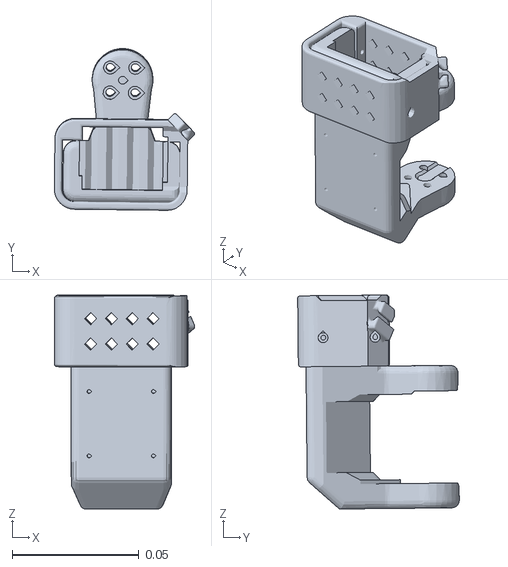
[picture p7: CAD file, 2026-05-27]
src/alohax_urdf/meshes/right_link1.STL
0.0553 x 0.0638 x 0.0844

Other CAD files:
install/alohax_urdf/share/alohax_urdf/meshes/left_link4.STL
install/alohax_urdf/share/alohax_urdf/meshes/left_link1.STL
src/alohax_urdf/meshes/left_base.STL
install/alohax_urdf/share/alohax_urdf/meshes/left_link3.STL
install/alohax_urdf/share/alohax_urdf/meshes/AstraPlus.stl
install/alohax_urdf/share/alohax_urdf/meshes/left_link2.STL
install/alohax_urdf/share/alohax_urdf/meshes/left_link5.STL
install/alohax_urdf/share/alohax_urdf/meshes/right_link1.STL
install/alohax_urdf/share/alohax_urdf/meshes/right_link5.STL
install/alohax_urdf/share/alohax_urdf/meshes/right_link3.STL
install/alohax_urdf/share/alohax_urdf/meshes/base_body.stl
install/alohax_urdf/share/alohax_urdf/meshes/left_base.STL
install/alohax_urdf/share/alohax_urdf/meshes/left_link6.STL
install/alohax_urdf/share/alohax_urdf/meshes/raskog_basket.stl
install/alohax_urdf/share/alohax_urdf/meshes/raskogwheel1.stl
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

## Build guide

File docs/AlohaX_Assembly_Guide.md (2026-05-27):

# AlohaX Assembly Guide

AlohaX is a dual-arm four-wheel humanoid robot based on AlohaMini architecture, combining xlerobot's mobile base design. This guide details the AlohaX assembly process.

---

## Preparation

Before starting AlohaX assembly, ensure you have:
1. Completed procurement of all components (see [AlohaX_BOM.md](AlohaX_BOM.md))
2. Completed printing of all 3D printed parts
3. Prepared necessary tools (screwdriver set, soldering iron, bench vise, etc.)
4. Prepared auxiliary materials such as cable ties, heat shrink tubing, etc.

---

## 1. Body Assembly

### 1.1 Head Camera Installation

Head camera for visual perception, AlohaX is equipped with multiple cameras.

1. **Preparation**
   - Take out USB camera (720p, focal length 2.1mm)
   - Prepare M2×12 Phillips screws

2. **Assembly Steps**
   - Mount camera to head bracket
   - Secure with M2×12 screws
   - Connect camera USB cable, route through pipe

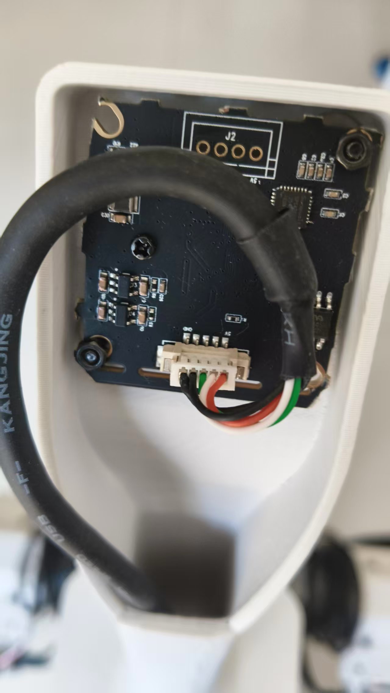
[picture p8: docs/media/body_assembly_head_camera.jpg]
Head Camera Installation


### 1.2 Body Main Assembly

Body main part based on AlohaMini design, core component of robot.

1. **Preparation**
   - Take out 3D printed body main frame
   - Prepare 302 glue

2. **Assembly Steps**
   - Cut off excess at bottom, align upper and lower shells of body main part, secure sequentially with 302 glue

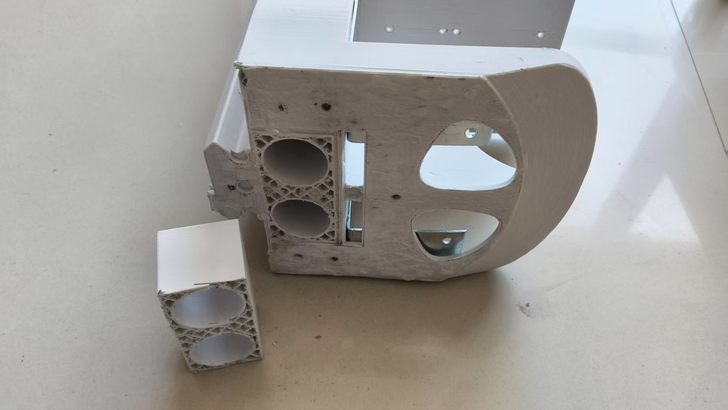
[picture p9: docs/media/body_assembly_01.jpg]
Body Assembly 01

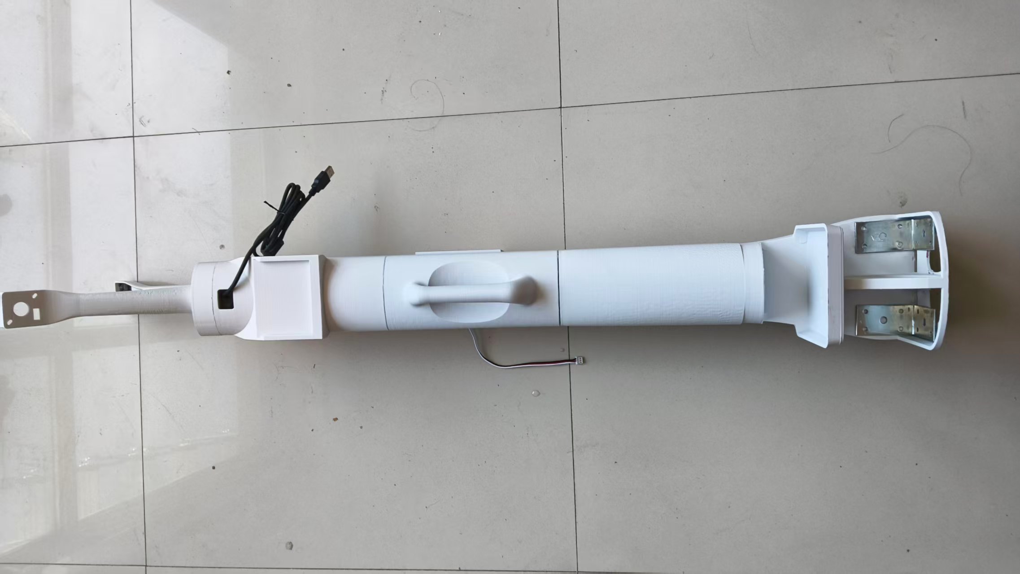
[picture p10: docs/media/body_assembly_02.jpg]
Body Assembly 02


### 1.3 Steel Pipe or Aluminum Pipe Installation (Optional)

Steel pipe for reinforcing body structure and lift mechanism, select 2 steel pipes or aluminum pipes with outer diameter 29mm, thickness no more than 2mm, length 800mm. Too thick will make robot front too heavy.

1. **Preparation**
   - Take out steel pipes
   - Prepare adhesive (epoxy recommended)

2. **Assembly Steps**
   - Insert steel pipes into reserved holes in body main part
   - Secure steel pipes with epoxy, ensure vertical and firm
   - Wait for adhesive to fully cure

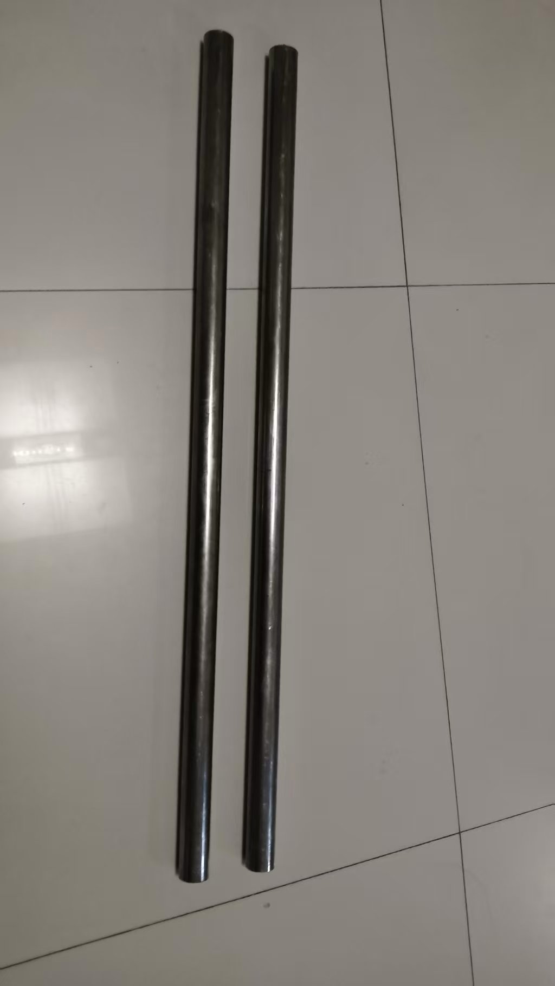
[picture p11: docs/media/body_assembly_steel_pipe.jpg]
Steel Pipe Installation

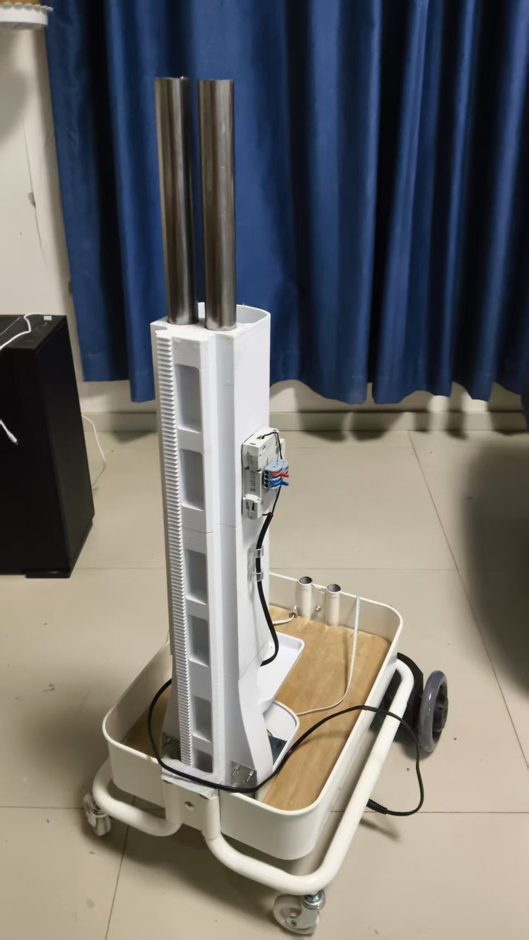
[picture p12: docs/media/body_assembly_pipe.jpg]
Steel Pipe Installation


### 1.4 Vertical Lift Mechanism Assembly

Vertical lift mechanism is one of AlohaX's core features, can expand working range.

1. **Preparation**
   - Take out lift axis assembly
   - Take out gears and transmission components
   - Prepare servo (ID 11 allocation completed)

2. **Assembly Steps**
   - Mount lift axis to body main part guide rails
   - Install gear set, ensure smooth meshing
   - Connect servo, test lift motion

> **Tip**: Ensure lift motion is smooth, no jamming or abnormal noise.

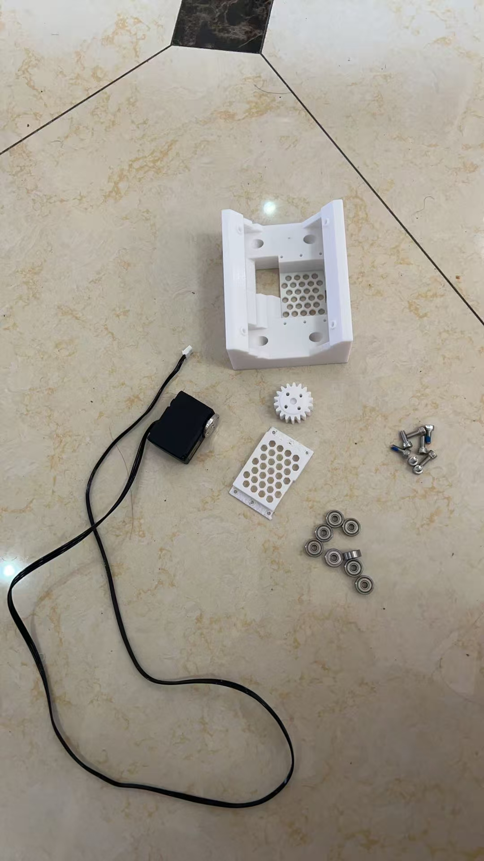
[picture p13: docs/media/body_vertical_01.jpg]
Vertical Lift 01

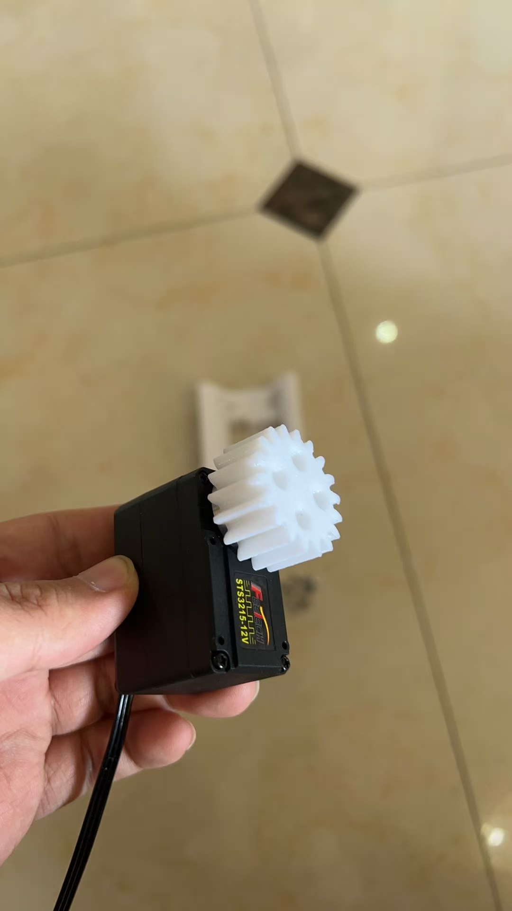
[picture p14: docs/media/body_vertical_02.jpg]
Vertical Lift 02

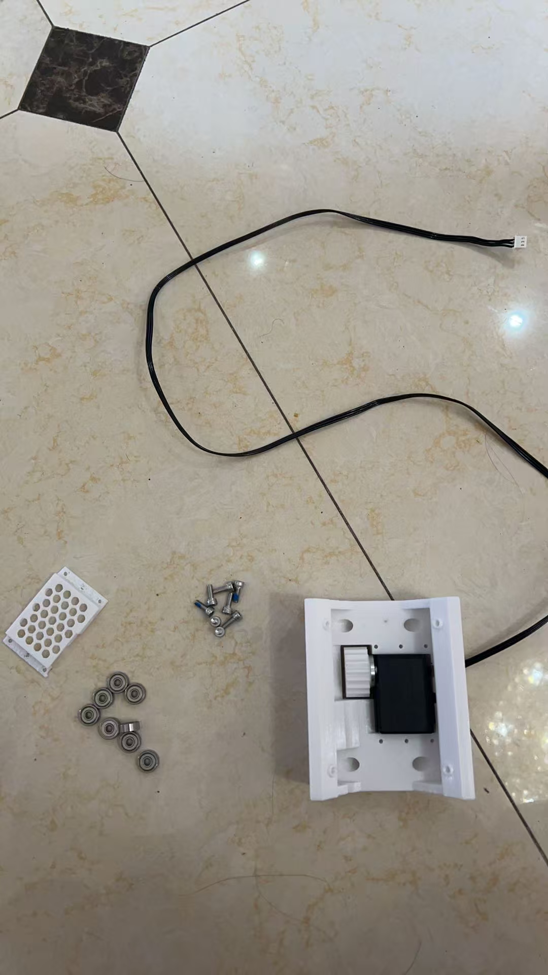
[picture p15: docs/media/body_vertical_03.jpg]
Vertical Lift 03

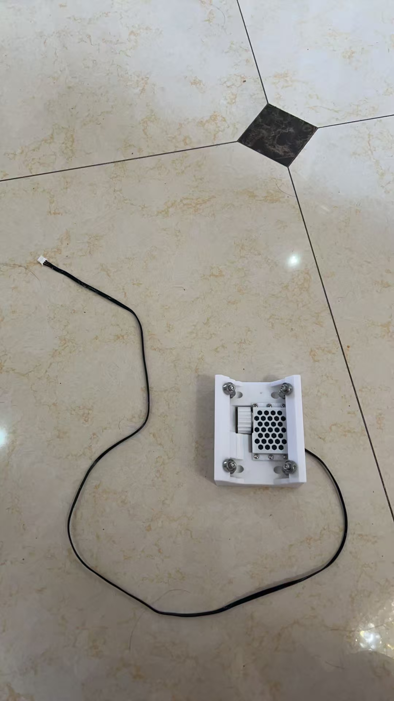
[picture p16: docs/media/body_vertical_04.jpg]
Vertical Lift 04

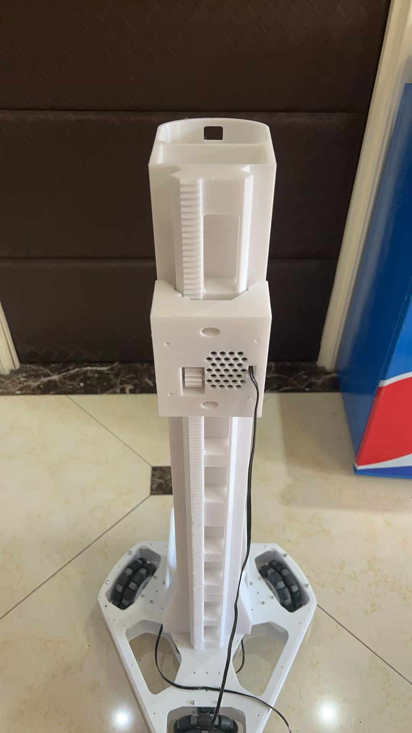
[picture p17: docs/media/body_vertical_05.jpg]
Vertical Lift 05

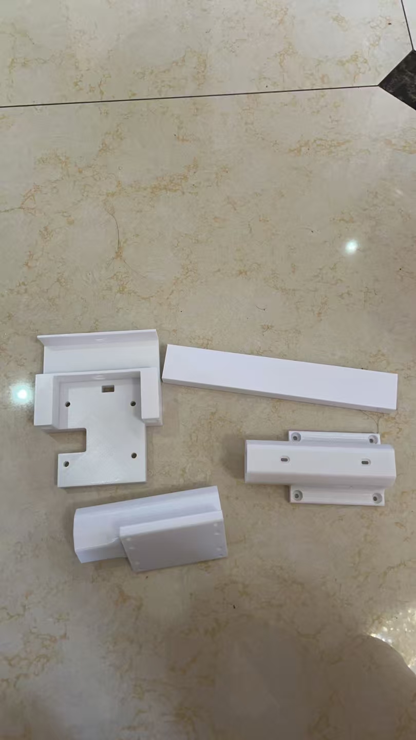
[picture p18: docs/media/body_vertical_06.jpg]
Vertical Lift 06

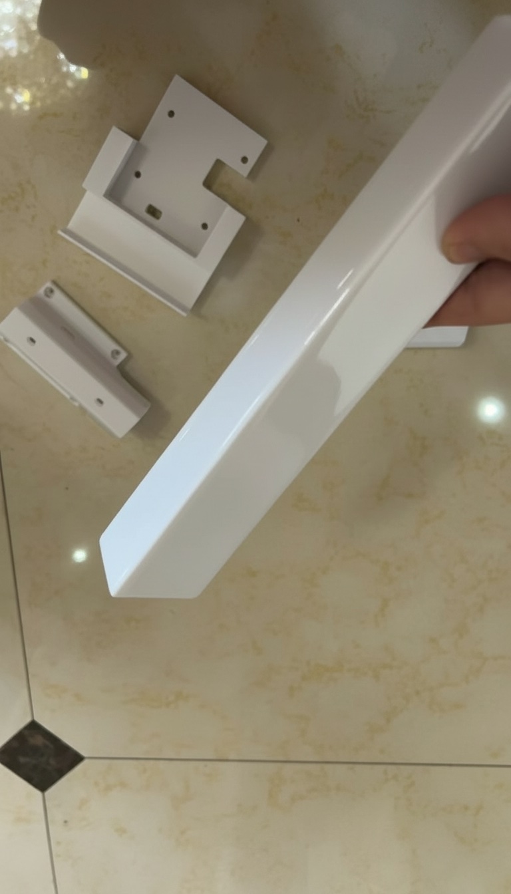
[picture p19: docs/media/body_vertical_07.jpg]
Vertical Lift 07

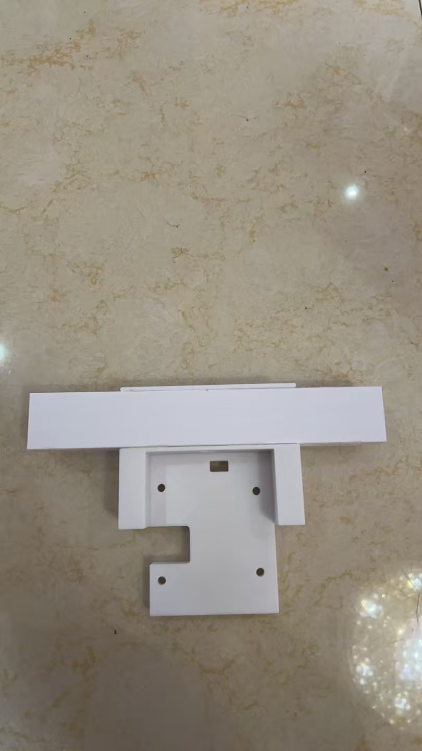
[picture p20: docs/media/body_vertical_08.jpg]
Vertical Lift 08

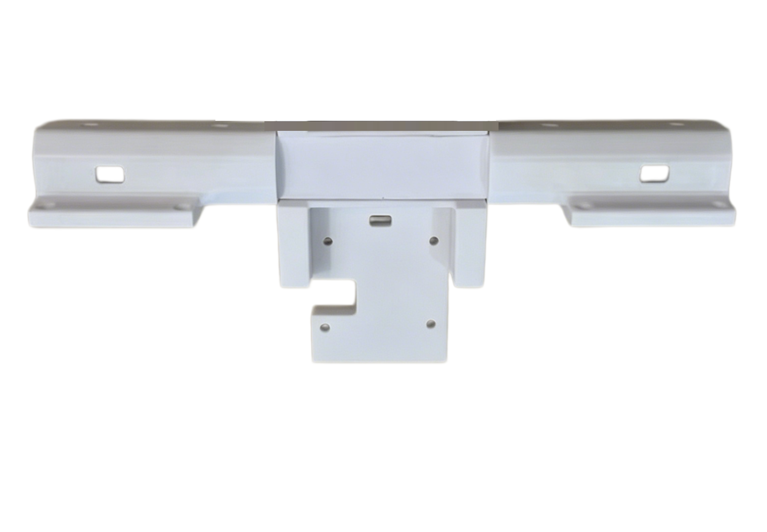
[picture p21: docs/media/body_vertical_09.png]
Vertical Lift 09

> **Important Note**: AlohaX arms are mounted below body, so lift mechanism arm mounting bracket faces downward, opposite to AlohaMini direction.

### 1.5 USB Hub Installation

USB Hub is robot's communication hub, for connecting multiple devices.
USB Hub placed above chest core module, secured with 302 glue or strong double-sided tape, power terminal below, reduces overall wiring length.

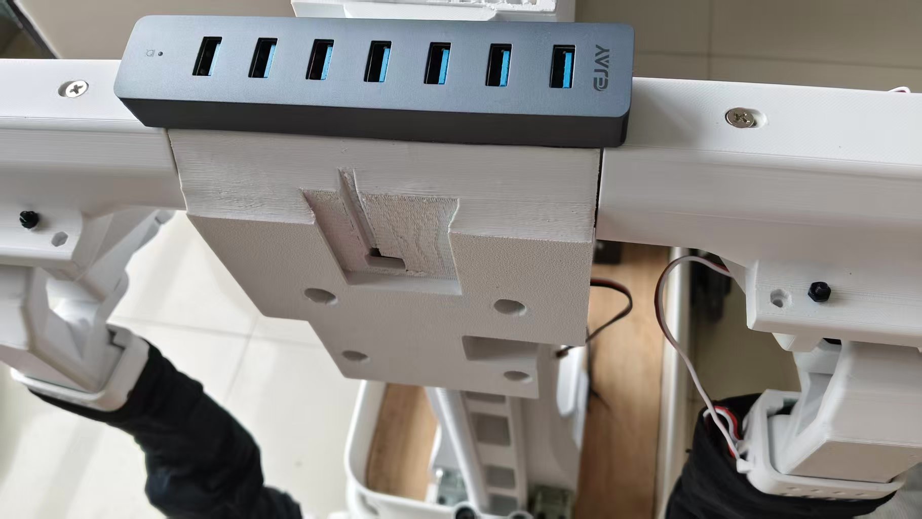
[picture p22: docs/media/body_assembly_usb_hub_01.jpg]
USB Hub Installation


---

## 2. Base Assembly

Base uses IKEA Raskog cart modification, robot's mobile platform.

### 2.1 Cart Modification

1. **Preparation**
   - Take out IKEA Raskog cart
   - Prepare wood board, screws, and tools

2. **Modification Steps**
   - Retain only bottom basket, remove other shelves, cut Raskog steel pipe at bottom basket
   - Compared to xlerobot, rotate base 90 degrees for more coordinated aspect ratio
   - Cut wood board to same shape as basket interior, install in base basket
   - Secure wood board with self-tapping screws, ensure stable

### 2.2 Drive System Installation

1. **Preparation**
   - Take out 2 servos (ID 7, 8)
   - Take out driving wheels and driven wheels
   - Prepare servo mounting brackets

2. **Assembly Steps**
   - Mount servos to base designated positions
   - Install driving wheels to servo output shafts
   - Install driven wheels to corresponding brackets
   - Connect servo cables to bus servo controller

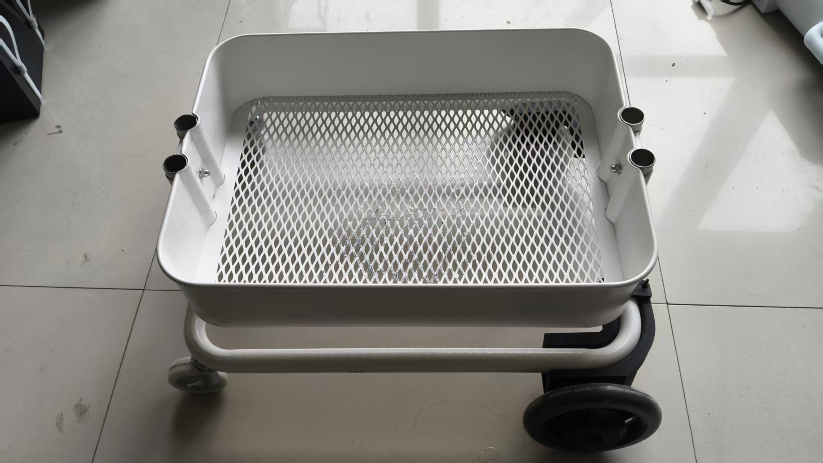
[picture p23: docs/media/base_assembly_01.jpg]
Base Assembly 01

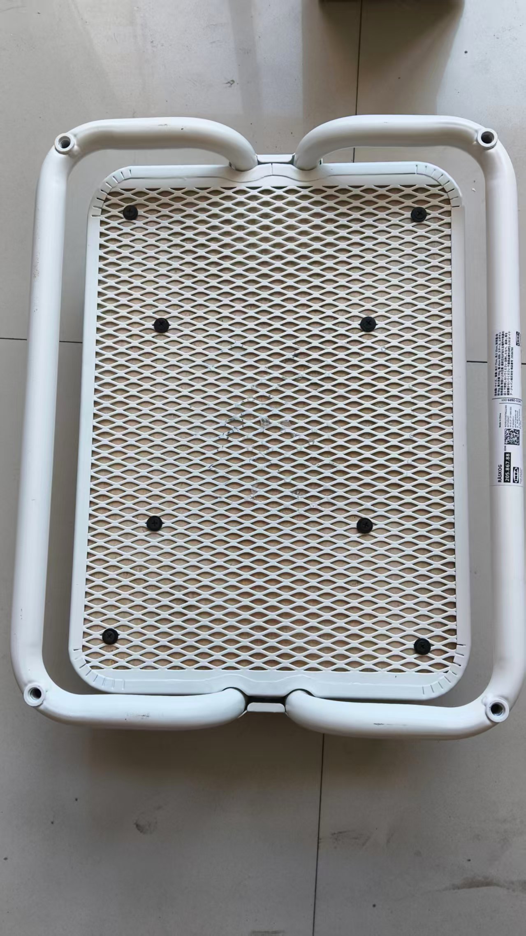
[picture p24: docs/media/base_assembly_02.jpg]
Base Assembly 02

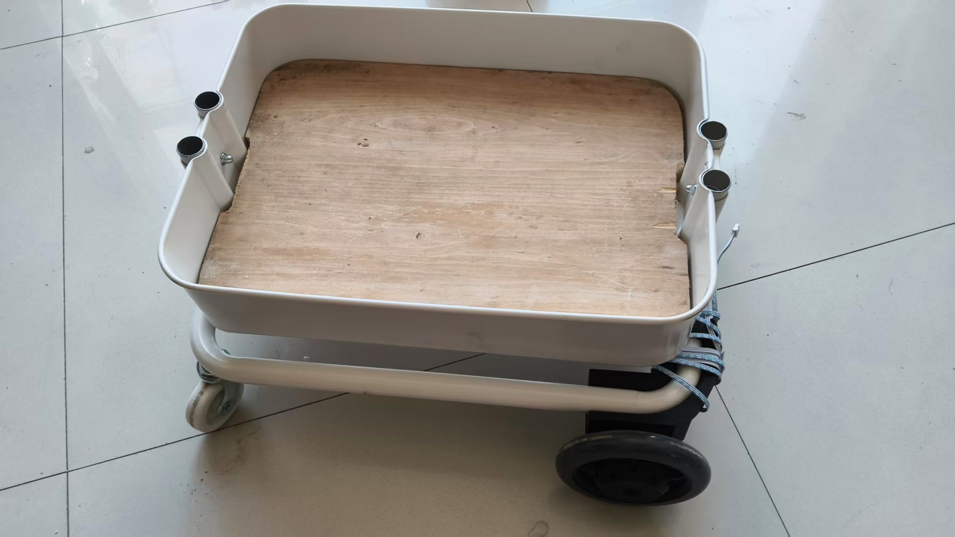
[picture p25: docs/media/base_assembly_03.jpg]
Base Assembly 03


> **Note**: Uses IKEA Raskog cart as mobile base, retains only bottom basket, and adds wood board reinforcement, solves base softness and motion wobble issues.
xlerobot0.4.0 assembly reference official site:
https://xlerobot.readthedocs.io/en/latest/hardware/getting_started/assemble_2wheel.html

---

## 3. Final Assembly

### 3.1 Slave Arm Installation

AlohaX is equipped with two SO-ARM101 slave arms.

**Slave arm installation reference official guide**: [SO-101 Assembly Guide](https://huggingface.co/docs/lerobot/so101)

> **Note**: Arms directly reuse SO-ARM100/SO-ARM101 design, if you already have two SO-ARM101 arms, you can use them directly.

### 3.2 Body and Base Assembly

Mount assembled body module to base.

1. **Preparation**
   - Ensure body and base are both assembled
   - Prepare angle brackets and M3×18 self-tapping screws

2. **Assembly Steps**
   - Align body module to base front mounting positions
   - Secure body module with angle brackets and self-tapping screws
   - Check if connection is firm, adjust position to ensure vertical

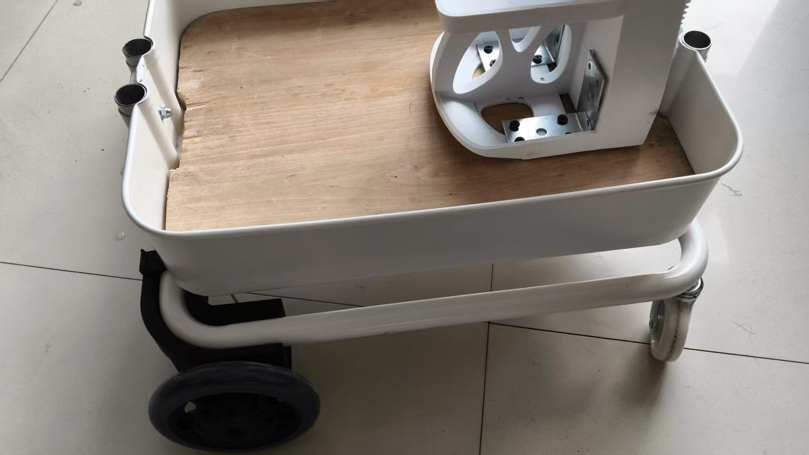
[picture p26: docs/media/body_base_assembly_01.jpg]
Body Base Assembly 01

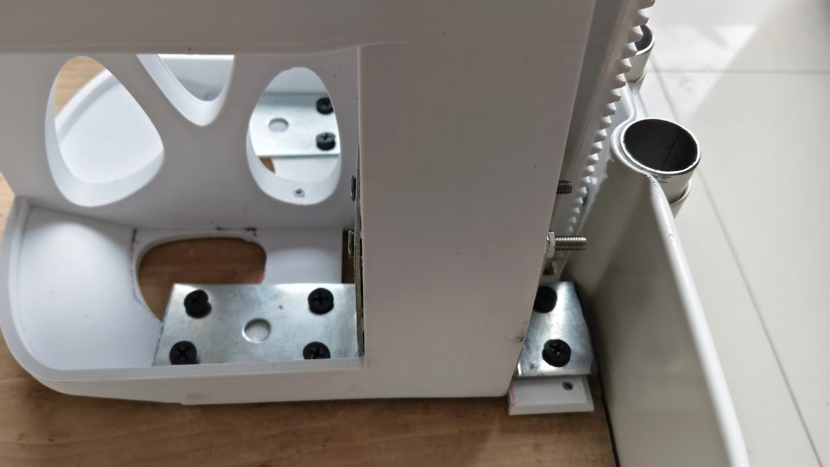
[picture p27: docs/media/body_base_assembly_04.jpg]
Body Base Assembly 04


### 3.3 Slave Arm and Mobile Base Assembly

Mount slave arms to body module.

1. **Preparation**
   - Take out assembled slave arms
   - Prepare M2×30 hex socket screws and M3 nuts

2. **Assembly Steps**
   - Use four M2×30 hex socket screws and four M3 nuts to secure arms to both sides of T-bracket
   - Connect 90cm servo cable of servo #11 to another port of left arm's Waveshare control board
   - Route dual arm driver/camera USB cables around shoulders
   - Servo cables recommended to use twisted pairs, improves anti-interference

> **Wiring Tip**: Except for battery to power terminal cables, all other cables fixed to body core, aesthetic and tangle-free.

### 3.4 Wiring

#### 3.4.1 Battery Assembly

Battery is robot's power source.

1. **Preparation**
   - Take out 12V 20A lead-acid battery
   - Prepare battery multi-socket cover

2. **Assembly Steps**
   - Cover battery switch socket cover onto 12V battery, secure firmly with cable ties
   - Connect battery positive and negative to circuit breaker

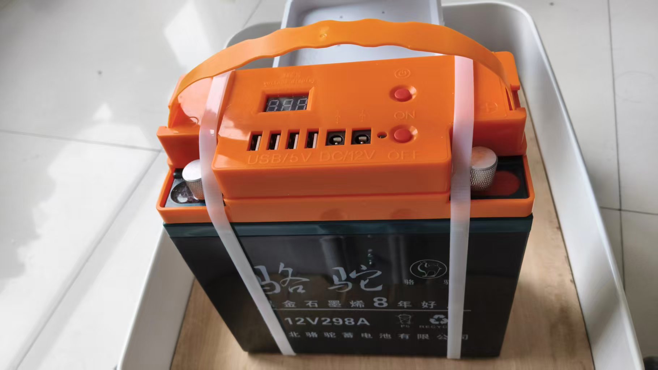
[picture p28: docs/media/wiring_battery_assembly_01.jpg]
Battery Assembly


#### 3.4.2 Circuit Breaker

Circuit breaker for overcurrent protection and emergency stop function.

1. **Preparation**
   - Take out 6A DC circuit breaker

2. **Assembly Steps**
   - Mount circuit breaker to body side, secure with 302 glue or strong double-sided tape
   - Connect input and output power cables
   - Test circuit breaker function, ensure can normally cut power

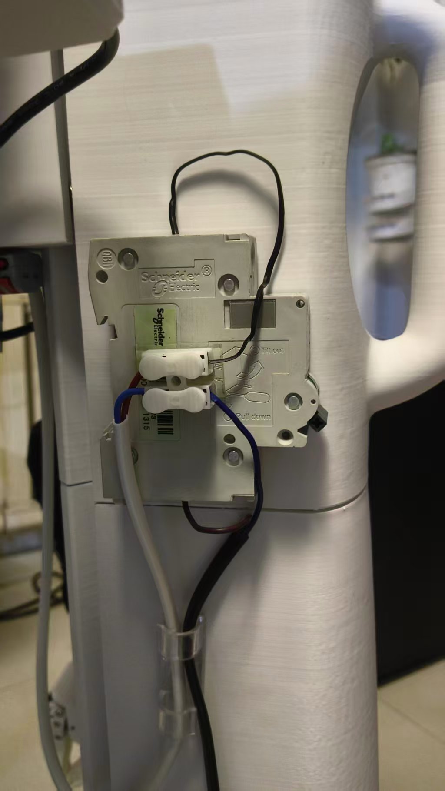
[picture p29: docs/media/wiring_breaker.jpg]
Circuit Breaker Installation


#### 3.4.3 12V Connector

12V connector for connecting battery and various electrical devices.

1. **Preparation**
   - Take out 12V 2-6 terminal block
   - Take out 3 12V cables with plugs, Orin nano power plug interface is 5525, Waveshare control board plug is 5521.

2. **Assembly Steps**
   - Connect terminal block input positive and negative to circuit breaker output terminals with wires.
   - Connect terminal block outputs to Orin nano main controller, left arm, right arm Waveshare control boards respectively.

> **Important Note**: Jetson nano, Raspberry Pi and other 5V powered main controllers, do not connect to 12V! Can take power from USB port on battery cover.

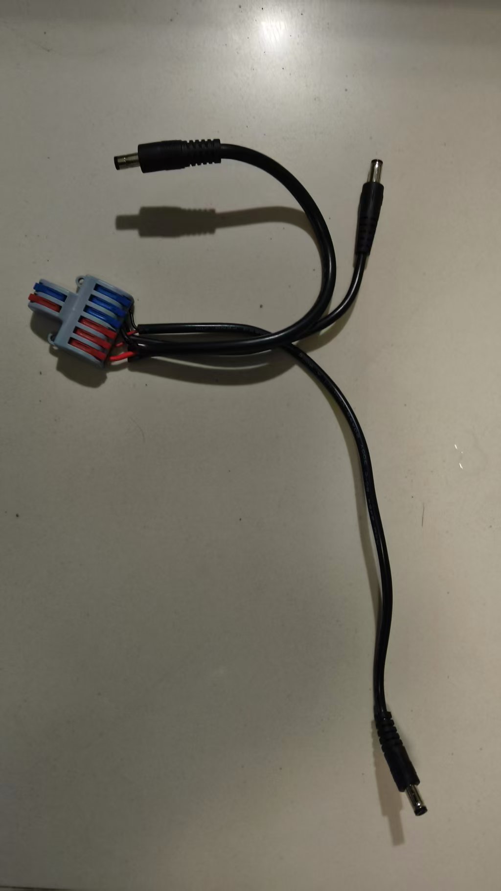
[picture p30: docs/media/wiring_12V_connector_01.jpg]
12V Connector 02

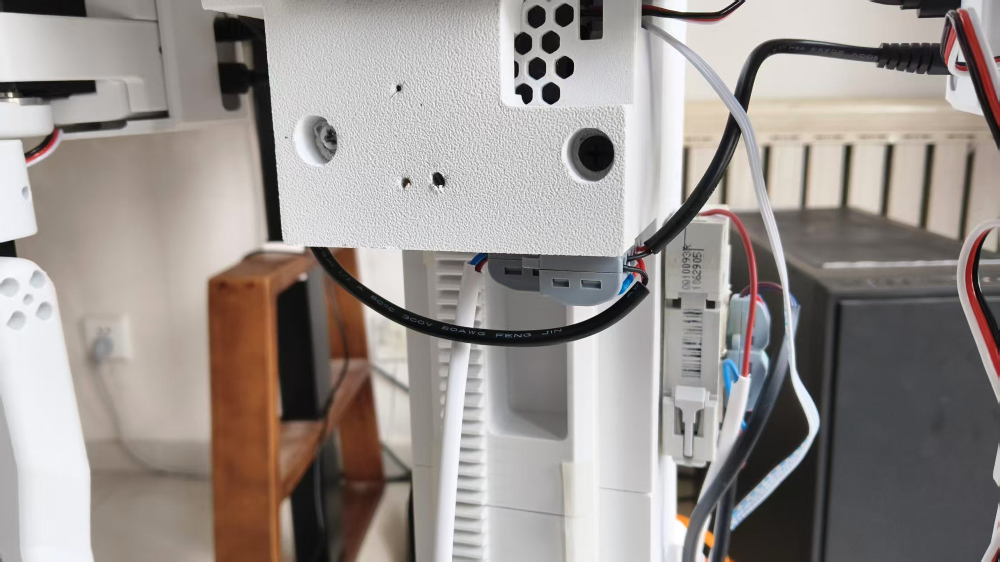
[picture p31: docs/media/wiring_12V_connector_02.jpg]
12V Connector 03


#### 3.4.4 USB Hub Wiring

USB Hub for connecting all USB devices.

1. **Preparation**
   - Take out USB Hub
   - Prepare USB cables

2. **Assembly Steps**
   - Connect dual arm camera USB cables to USB Hub
   - Connect dual arm controller USB cables to USB Hub
   - Organize cables, excess cables wrapped around robot shoulders, secured with cable ties

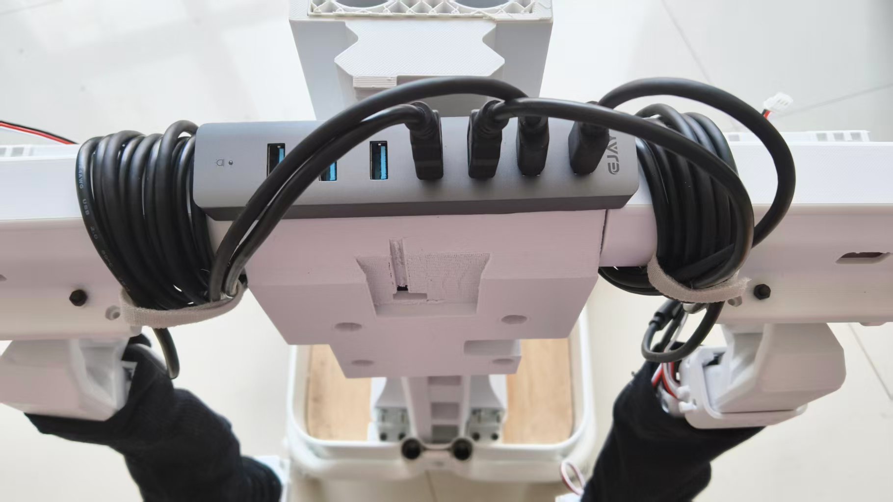
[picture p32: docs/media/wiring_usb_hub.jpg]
USB Hub Wiring


#### 3.4.5 Astra Pro Camera Wiring

Astra Pro for depth perception (if applicable).

1. **Preparation**
   - Take out Astra Pro camera (if equipped)
   - Prepare USB cable

2. **Assembly Steps**
   - Attach Astra Pro base to robot core with 302 glue, or drill holes outward from core interior, secure Astra Pro base with M6 bolts.
   - Connect USB cable to USB Hub
   - Secure cable, avoid affecting motion

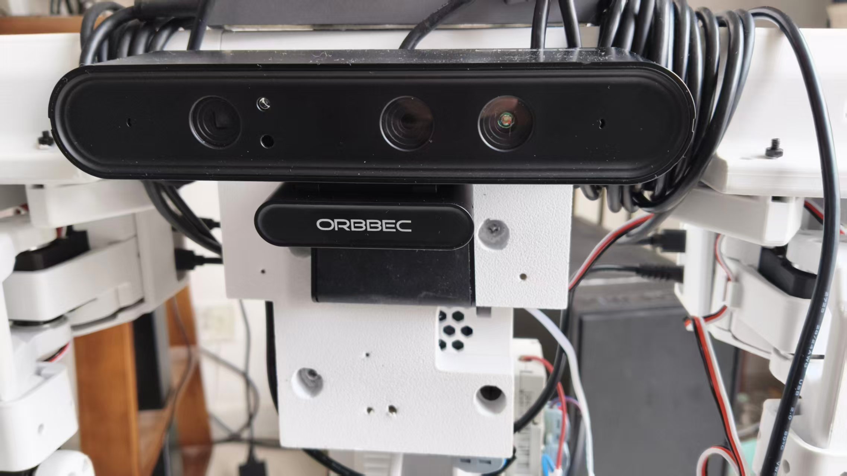
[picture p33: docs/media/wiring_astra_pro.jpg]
Astra Pro Wiring


#### 3.4.6 Orin Nano Connection

Main controller is robot's computing core.

1. **Preparation**
   - Take out NVIDIA Orin nano main controller (or Raspberry Pi/PC)

2. **Assembly Steps**
   - Attach main controller to robot body back or lower mounting platform with 302 glue or strong double-sided tape
   - Connect buck converter output to main controller power input (for Raspberry Pi or Jetson nano)
   - Connect USB Hub to main controller
   - Connect other peripherals (such as display, optional)

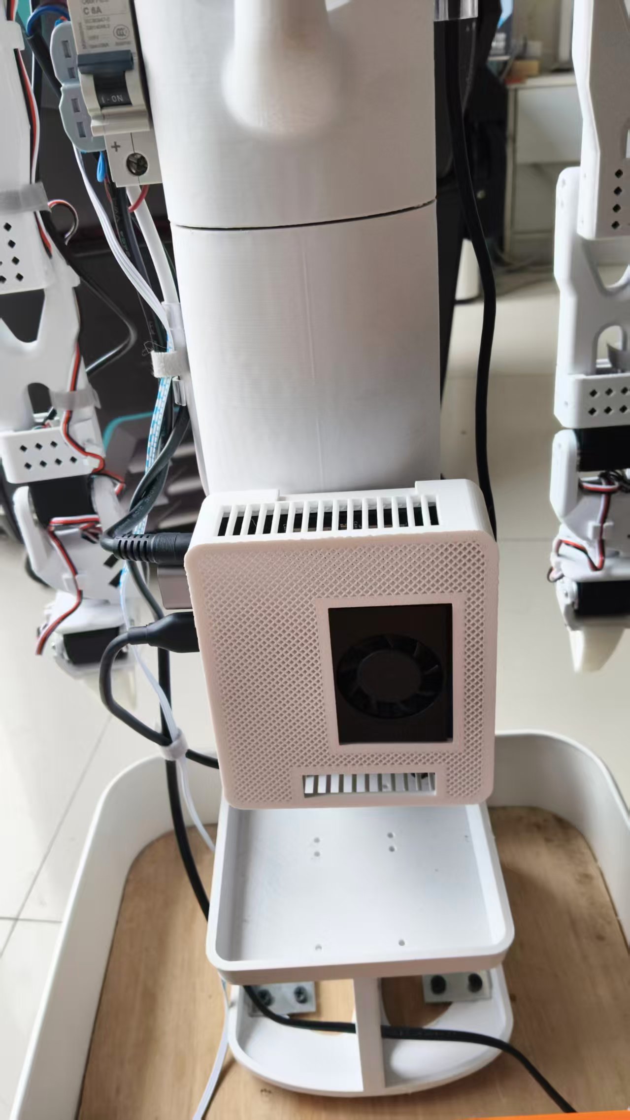
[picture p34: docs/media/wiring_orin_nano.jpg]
Orin Nano Connection


### 3.6 Assembly Completion Check

1. **Mechanical Check**
   - Check if all screws are tightened
   - Check if all moving parts move smoothly
   - Check if cables have wear risk

2. **Electrical Check**
   - Check if all connectors are firm
   - Check if power cable positive and negative are correct
   - Test circuit breaker function

3. **Functional Check**
   - Test if lift mechanism is smooth
   - Test if mobile base can move normally
   - Test if arms can move normally
   - Check if camera can work normally

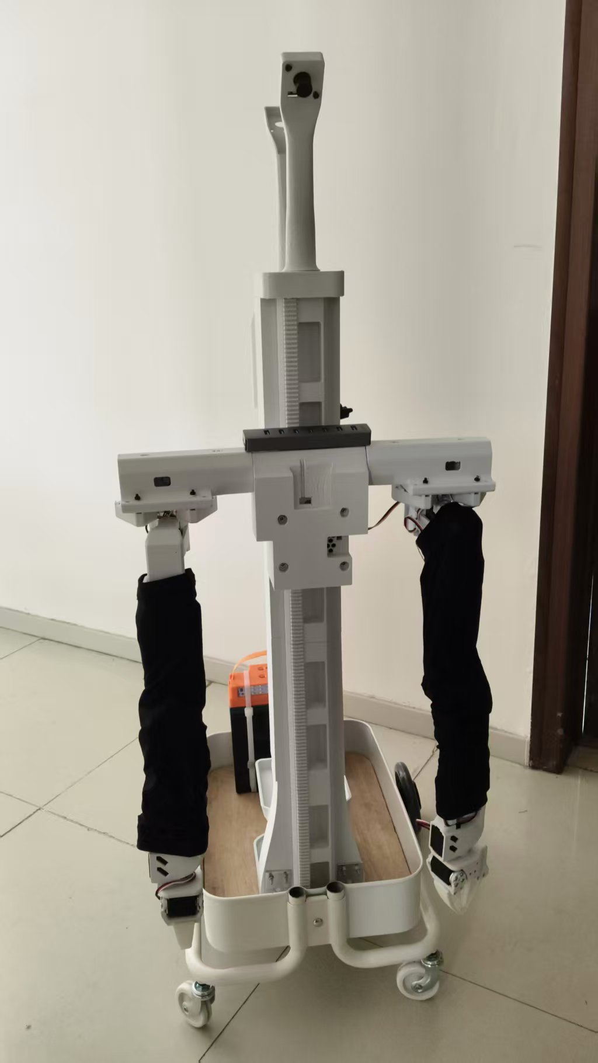
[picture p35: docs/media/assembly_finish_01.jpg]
Assembly Completion Check 01

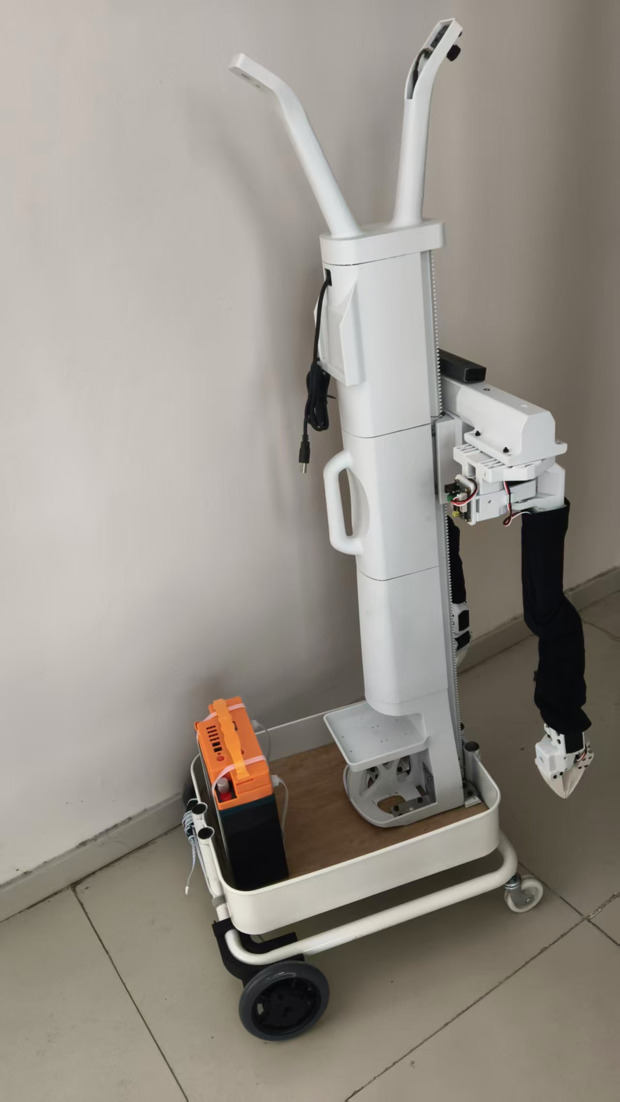
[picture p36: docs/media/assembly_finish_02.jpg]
Assembly Completion Check 02

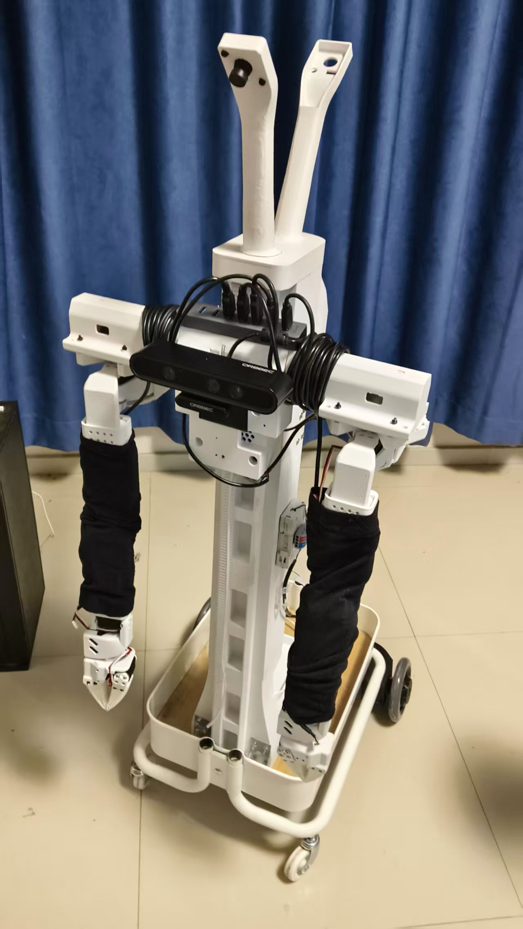
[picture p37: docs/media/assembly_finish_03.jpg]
Assembly Completion Check 03


---

## Safety Notes

- **Charging Safety**: Only connect battery during operation, disconnect entire robot wiring during charging (most chargers output 14.6V, higher than maximum 12.6V input specified for Waveshare control board).
- **Operation Safety**: Ensure surrounding safety during robot operation, prevent personal injury or equipment damage.
- **Emergency Stop Usage**: Use DC circuit breaker to cut power in emergency situations.
- **Long-term Storage**: Disconnect battery connection when not using for long time, prevent battery over-discharge.

---

## FAQ

### Q1: Servo communication abnormal
**A**: Check if servo ID is correctly allocated, check if cable connection is firm, check bus terminal resistor configuration.

### Q2: Lift mechanism jamming
**A**: Check if gear meshing is normal, check if guide rails have foreign objects, check if servo torque is sufficient.

### Q3: USB device disconnection
**A**: Check if USB cable is loose, recommend using twisted pairs to improve anti-interference, check if power supply is stable.

---

## Appendix

### Servo ID Allocation Table

| Servo Position | ID | Description |
|---|----|---|
| Base left rear wheel | 7 | Driving wheel drive |
| Base right rear wheel | 8 | Driving wheel drive |
| Lift mechanism | 11 | For body core and dual arm lift |
| Left arm joints | 1-6 | Slave arm joints |
| Right arm joints | 1-6 | Slave arm joints |

> **Tip**: Base two wheels and lift mechanism servos are all connected to left arm Waveshare control board, share one control board with left arm. Specific ID allocation may vary based on configuration, please adjust according to actual situation.

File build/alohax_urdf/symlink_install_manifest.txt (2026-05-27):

/home/seeed/alohax_ws/install/alohax_urdf/share/alohax_urdf//meshes/AstraPlus.stl
/home/seeed/alohax_ws/install/alohax_urdf/share/alohax_urdf//meshes/base_body.dae
/home/seeed/alohax_ws/install/alohax_urdf/share/alohax_urdf//meshes/base_body.stl
/home/seeed/alohax_ws/install/alohax_urdf/share/alohax_urdf//meshes/left_base.STL
/home/seeed/alohax_ws/install/alohax_urdf/share/alohax_urdf//meshes/left_link1.STL
/home/seeed/alohax_ws/install/alohax_urdf/share/alohax_urdf//meshes/left_link2.STL
/home/seeed/alohax_ws/install/alohax_urdf/share/alohax_urdf//meshes/left_link3.STL
/home/seeed/alohax_ws/install/alohax_urdf/share/alohax_urdf//meshes/left_link4.STL
/home/seeed/alohax_ws/install/alohax_urdf/share/alohax_urdf//meshes/left_link5.STL
/home/seeed/alohax_ws/install/alohax_urdf/share/alohax_urdf//meshes/left_link6.STL
/home/seeed/alohax_ws/install/alohax_urdf/share/alohax_urdf//meshes/raskog_basket.dae
/home/seeed/alohax_ws/install/alohax_urdf/share/alohax_urdf//meshes/raskog_basket.stl
/home/seeed/alohax_ws/install/alohax_urdf/share/alohax_urdf//meshes/raskogwheel1.dae
/home/seeed/alohax_ws/install/alohax_urdf/share/alohax_urdf//meshes/raskogwheel1.stl
/home/seeed/alohax_ws/install/alohax_urdf/share/alohax_urdf//meshes/raskogwheel2.dae
/home/seeed/alohax_ws/install/alohax_urdf/share/alohax_urdf//meshes/raskogwheel2.stl
/home/seeed/alohax_ws/install/alohax_urdf/share/alohax_urdf//meshes/right_base.STL
/home/seeed/alohax_ws/install/alohax_urdf/share/alohax_urdf//meshes/right_link1.STL
/home/seeed/alohax_ws/install/alohax_urdf/share/alohax_urdf//meshes/right_link2.STL
/home/seeed/alohax_ws/install/alohax_urdf/share/alohax_urdf//meshes/right_link3.STL
/home/seeed/alohax_ws/install/alohax_urdf/share/alohax_urdf//meshes/right_link4.STL
/home/seeed/alohax_ws/install/alohax_urdf/share/alohax_urdf//meshes/right_link5.STL
/home/seeed/alohax_ws/install/alohax_urdf/share/alohax_urdf//meshes/right_link6.STL
/home/seeed/alohax_ws/install/alohax_urdf/share/alohax_urdf//meshes/vertical_link.STL
/home/seeed/alohax_ws/install/alohax_urdf/share/alohax_urdf//meshes/wheel1.STL
/home/seeed/alohax_ws/install/alohax_urdf/share/alohax_urdf//meshes/wheel2.STL
/home/seeed/alohax_ws/install/alohax_urdf/share/alohax_urdf//urdf/alohax (Copy).urdf
/home/seeed/alohax_ws/install/alohax_urdf/share/alohax_urdf//urdf/alohax.csv
/home/seeed/alohax_ws/install/alohax_urdf/share/alohax_urdf//urdf/alohax.urdf
/home/seeed/alohax_ws/install/alohax_urdf/share/alohax_urdf//textures/init.py
/home/seeed/alohax_ws/install/alohax_urdf/share/alohax_urdf//config/joint_names_Aloha.yaml
/home/seeed/alohax_ws/install/alohax_urdf/share/alohax_urdf//launch/display.launch
/home/seeed/alohax_ws/install/alohax_urdf/share/alohax_urdf//launch/display.launch.py
/home/seeed/alohax_ws/install/alohax_urdf/share/alohax_urdf//launch/gazebo.launch
/home/seeed/alohax_ws/install/alohax_urdf/share/alohax_urdf//rviz/urdf.rviz
/home/seeed/alohax_ws/install/alohax_urdf/lib/alohax_urdf//marker_publisher.py
/home/seeed/alohax_ws/install/alohax_urdf/share/ament_index/resource_index/package_run_dependencies/alohax_urdf
/home/seeed/alohax_ws/install/alohax_urdf/share/ament_index/resource_index/parent_prefix_path/alohax_urdf
/home/seeed/alohax_ws/install/alohax_urdf/share/alohax_urdf/environment/ament_prefix_path.sh
/home/seeed/alohax_ws/install/alohax_urdf/share/alohax_urdf/environment/ament_prefix_path.dsv
/home/seeed/alohax_ws/install/alohax_urdf/share/alohax_urdf/environment/path.sh
/home/seeed/alohax_ws/install/alohax_urdf/share/alohax_urdf/environment/path.dsv
/home/seeed/alohax_ws/install/alohax_urdf/share/alohax_urdf/local_setup.bash
/home/seeed/alohax_ws/install/alohax_urdf/share/alohax_urdf/local_setup.sh
/home/seeed/alohax_ws/install/alohax_urdf/share/alohax_urdf/local_setup.zsh
/home/seeed/alohax_ws/install/alohax_urdf/share/alohax_urdf/local_setup.dsv
/home/seeed/alohax_ws/install/alohax_urdf/share/alohax_urdf/package.dsv
/home/seeed/alohax_ws/install/alohax_urdf/share/ament_index/resource_index/packages/alohax_urdf
/home/seeed/alohax_ws/install/alohax_urdf/share/alohax_urdf/cmake/alohax_urdfConfig.cmake
/home/seeed/alohax_ws/install/alohax_urdf/share/alohax_urdf/cmake/alohax_urdfConfig-version.cmake
/home/seeed/alohax_ws/install/alohax_urdf/share/alohax_urdf/package.xml

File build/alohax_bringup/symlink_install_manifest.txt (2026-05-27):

/home/seeed/alohax_ws/install/alohax_bringup/share/alohax_bringup/launch/alohax.launch.py
/home/seeed/alohax_ws/install/alohax_bringup/share/alohax_bringup/rviz/xlerobot_moveit.rviz
/home/seeed/alohax_ws/install/alohax_bringup/share/ament_index/resource_index/package_run_dependencies/alohax_bringup
/home/seeed/alohax_ws/install/alohax_bringup/share/ament_index/resource_index/parent_prefix_path/alohax_bringup
/home/seeed/alohax_ws/install/alohax_bringup/share/alohax_bringup/environment/ament_prefix_path.sh
/home/seeed/alohax_ws/install/alohax_bringup/share/alohax_bringup/environment/ament_prefix_path.dsv
/home/seeed/alohax_ws/install/alohax_bringup/share/alohax_bringup/environment/path.sh
/home/seeed/alohax_ws/install/alohax_bringup/share/alohax_bringup/environment/path.dsv
/home/seeed/alohax_ws/install/alohax_bringup/share/alohax_bringup/local_setup.bash
/home/seeed/alohax_ws/install/alohax_bringup/share/alohax_bringup/local_setup.sh
/home/seeed/alohax_ws/install/alohax_bringup/share/alohax_bringup/local_setup.zsh
/home/seeed/alohax_ws/install/alohax_bringup/share/alohax_bringup/local_setup.dsv
/home/seeed/alohax_ws/install/alohax_bringup/share/alohax_bringup/package.dsv
/home/seeed/alohax_ws/install/alohax_bringup/share/ament_index/resource_index/packages/alohax_bringup
/home/seeed/alohax_ws/install/alohax_bringup/share/alohax_bringup/cmake/alohax_bringupConfig.cmake
/home/seeed/alohax_ws/install/alohax_bringup/share/alohax_bringup/cmake/alohax_bringupConfig-version.cmake
/home/seeed/alohax_ws/install/alohax_bringup/share/alohax_bringup/package.xml

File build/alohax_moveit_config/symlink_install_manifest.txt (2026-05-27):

/home/seeed/alohax_ws/install/alohax_moveit_config/share/alohax_moveit_config/config/alohax.srdf
/home/seeed/alohax_ws/install/alohax_moveit_config/share/alohax_moveit_config/config/joint_limits.yaml
/home/seeed/alohax_ws/install/alohax_moveit_config/share/alohax_moveit_config/config/kinematics.yaml
/home/seeed/alohax_ws/install/alohax_moveit_config/share/alohax_moveit_config/config/moveit_controllers.yaml
/home/seeed/alohax_ws/install/alohax_moveit_config/share/alohax_moveit_config/config/ompl_planning.yaml
/home/seeed/alohax_ws/install/alohax_moveit_config/share/alohax_moveit_config/config/pilz_cartesian_limits.yaml
/home/seeed/alohax_ws/install/alohax_moveit_config/share/alohax_moveit_config/launch/move_group.launch.py
/home/seeed/alohax_ws/install/alohax_moveit_config/share/ament_index/resource_index/package_run_dependencies/alohax_moveit_config
/home/seeed/alohax_ws/install/alohax_moveit_config/share/ament_index/resource_index/parent_prefix_path/alohax_moveit_config
/home/seeed/alohax_ws/install/alohax_moveit_config/share/alohax_moveit_config/environment/ament_prefix_path.sh
/home/seeed/alohax_ws/install/alohax_moveit_config/share/alohax_moveit_config/environment/ament_prefix_path.dsv
/home/seeed/alohax_ws/install/alohax_moveit_config/share/alohax_moveit_config/environment/path.sh
/home/seeed/alohax_ws/install/alohax_moveit_config/share/alohax_moveit_config/environment/path.dsv
/home/seeed/alohax_ws/install/alohax_moveit_config/share/alohax_moveit_config/local_setup.bash
/home/seeed/alohax_ws/install/alohax_moveit_config/share/alohax_moveit_config/local_setup.sh
/home/seeed/alohax_ws/install/alohax_moveit_config/share/alohax_moveit_config/local_setup.zsh
/home/seeed/alohax_ws/install/alohax_moveit_config/share/alohax_moveit_config/local_setup.dsv
/home/seeed/alohax_ws/install/alohax_moveit_config/share/alohax_moveit_config/package.dsv
/home/seeed/alohax_ws/install/alohax_moveit_config/share/ament_index/resource_index/packages/alohax_moveit_config
/home/seeed/alohax_ws/install/alohax_moveit_config/share/alohax_moveit_config/cmake/alohax_moveit_configConfig.cmake
/home/seeed/alohax_ws/install/alohax_moveit_config/share/alohax_moveit_config/cmake/alohax_moveit_configConfig-version.cmake
/home/seeed/alohax_ws/install/alohax_moveit_config/share/alohax_moveit_config/package.xml

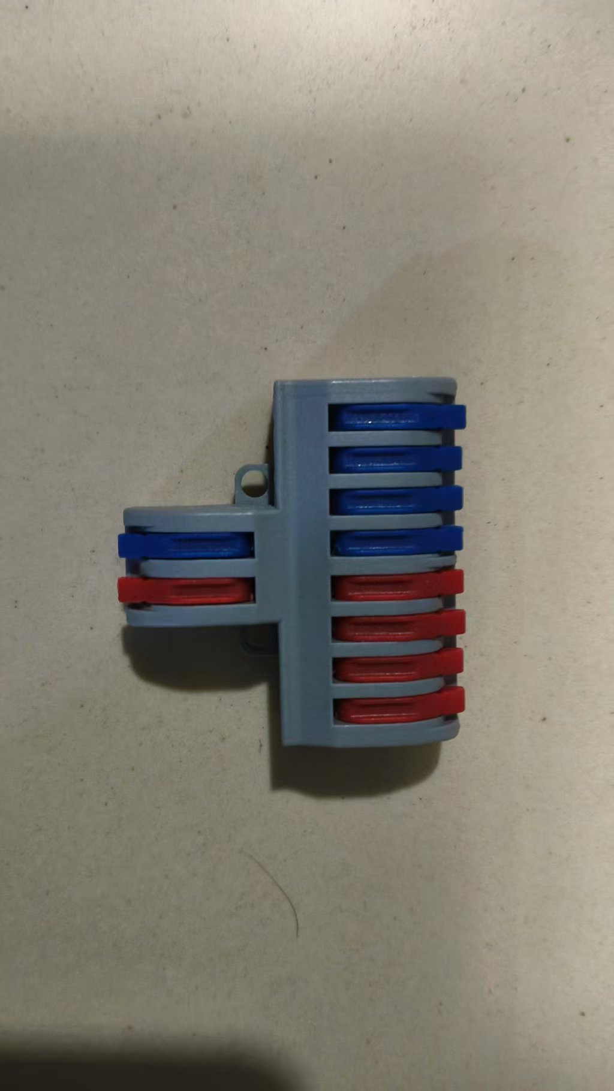
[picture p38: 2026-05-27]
docs/media/wiring_12V_connector.jpg

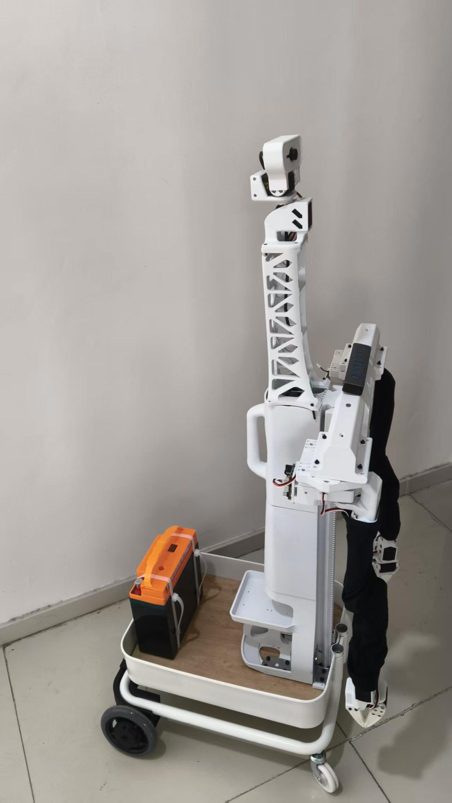
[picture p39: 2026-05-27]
docs/media/assembly_finish_head2DOF_01.jpg

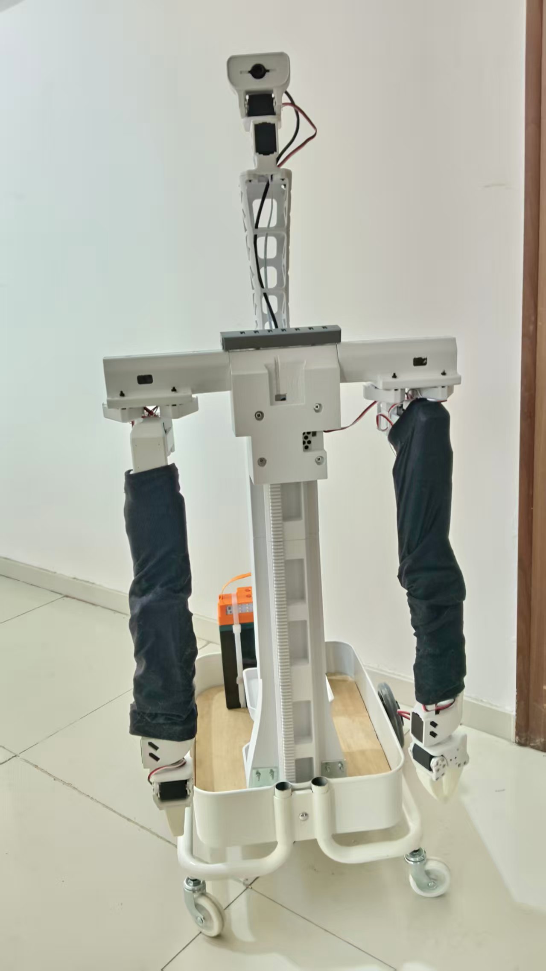
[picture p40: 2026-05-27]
docs/media/assembly_finish_head2DOF_02.jpg

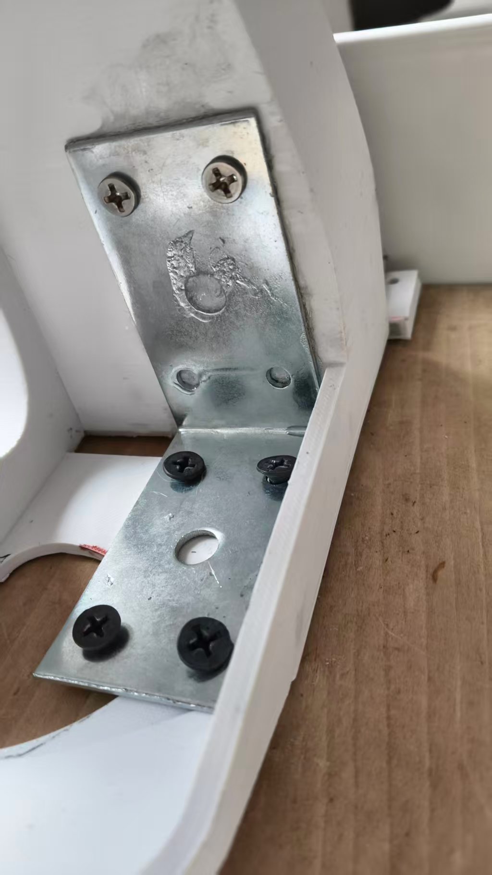
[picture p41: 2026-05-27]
docs/media/body_base_assembly_03.jpg

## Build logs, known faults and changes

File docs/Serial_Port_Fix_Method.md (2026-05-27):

# AlohaX Dual Arm Serial Port ttyACM Fix Method

Normally, ttyACM0 and ttyACM1 represent AlohaX robot's left and right arm Waveshare control board ports respectively. However, in cases of USB port plugging/unplugging or interference, the port numbers of the two Waveshare control boards may change, causing software to not find left or right arm. Using the following method can fix left and right arm port names.

## One-step Check Both Control Board Info (Direct Copy)

```bash
for port in /dev/ttyACM*; do
  echo "=== Device: $port ==="
  udevadm info -n $port -a | grep -E 'KERNELS|idVendor|idProduct|serial'
done
```

## Directly Generate Fixed Alias (Copy and Paste)

1. Create rules file
```bash
sudo nano /etc/udev/rules.d/99-robot-arms.rules
```
or
```bash
sudo nano /etc/udev/rules.d/99-so101.rules
```

2. Paste content below
Replace your serial number with the example string

```
## SO101 Robot Arm - Left ARM (serial: ***) → Fixed port /dev/so101_L
SUBSYSTEM=="tty", ATTRS{idVendor}=="1a86", ATTRS{idProduct}=="55d3", ATTRS{serial}=="fill_ttyACM0_serial_here", MODE="0666", SYMLINK+="so101_L"

## SO101 Robot Arm - Right ARM (serial: ***) → Fixed port /dev/so101_R
SUBSYSTEM=="tty", ATTRS{idVendor}=="1a86", ATTRS{idProduct}=="55d3", ATTRS{serial}=="fill_ttyACM1_serial_here", MODE="0666", SYMLINK+="so101_R"
```

3. Apply rules

Run
```bash
sudo udevadm control --reload-rules
sudo udevadm trigger
```

4. Verify success

Run
```bash
ls -l /dev/so101_L /dev/so101_R
```

Arrow pointing indicates success:
```
lrwxrwxrwx 1 root root 10 May 9 10:00 /dev/so101_L -> ttyACM0
lrwxrwxrwx 1 root root 10 May 9 10:00 /dev/so101_R -> ttyACM1
```

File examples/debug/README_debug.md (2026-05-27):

# AlohaX Debug Tools Usage Guide

## View All Motor States
```bash
python3 examples/debug/motors.py get_motors_states \
  --port /dev/ttyACM0
```
```bash
python3 examples/debug/motors.py get_motors_states \
  --port /dev/ttyACM1
```

## Control the Mobile Base Only
Use wsad & arrow keys to control the mobile base
```bash
python3 examples/debug/wheels.py \
   --port /dev/ttyACM0
```

## Control the Lift Axis Only
```bash
python3 examples/debug/axis.py \
   --port /dev/ttyACM0
```

## Rotate a Specific Motor by ID
```bash
python3 examples/debug/motors.py move_motor_to_position \
  --id 1 \
  --position 2 \
  --port /dev/ttyACM1
```

## Set a New Motor ID
```bash
python3 examples/debug/motors.py configure_motor_id \
  --id 10 \
  --set_id 8 \
  --port /dev/ttyACM0
```

## Set the Phase of a Specified Servo
```bash
python3 examples/debug/motors.py configure_motor_phase \
  --id 1 \
  --set_phase 12 \
  --port /dev/ttyACM0
```

## Set the Phase for All Servos
```bash
python3 examples/debug/motors.py configure_motor_phase \
  --set_phase 12 \
  --port /dev/ttyACM0
```

## Reset Current Position as the Motor Midpoint
```bash
python3 examples/debug/motors.py reset_motors_to_midpoint \
  --port /dev/ttyACM0

python3 examples/debug/motors.py reset_motors_to_midpoint \
  --port /dev/ttyACM1
```

## Disable Torque for All Arm Motors
```bash
python3 examples/debug/motors.py reset_motors_torque  \
  --port /dev/ttyACM0

python3 examples/debug/motors.py reset_motors_torque  \
  --port /dev/ttyACM1
```

## Execute an Action Script on the Robot Arm
```bash
python3 examples/debug/motors.py move_motors_by_script \
   --script_path action_scripts/test_dance.txt  \
   --port /dev/ttyACM0
```

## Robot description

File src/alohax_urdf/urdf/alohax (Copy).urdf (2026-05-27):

<?xml version="1.0" encoding="utf-8"?>
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
<robot name="alohax">
  <link name="base_body">
    <inertial>
      <origin xyz="-0.00084647910851246 0.00978916757496985 0.344753325406094" rpy="0 0 0" />
      <mass value="5.09802085015176" />
      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
    </inertial>
    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
  </link>
  <link name="wheel1">
    <inertial>
      <origin xyz="-5.2748796340582E-05 0.0157741139634841 -1.84430449176598E-07" rpy="0 0 0" />
      <mass value="0.19481896281763" />
      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
    </inertial>
    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
  </link>
  <joint name="base_left_wheel" type="continuous">
    <origin xyz="-0.2 0.25 0.05" rpy="0 0 0" />
    <parent link="raskog_basket" />
    <child link="wheel1" />
    <axis xyz="0 1 0" />
  </joint>
  <link name="wheel2">
    <inertial>
      <origin xyz="-6.44947300230958E-06 0.0157740656100239 -5.23561600380557E-05" rpy="0 0 0" />
      <mass value="0.194818035649416" />
      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
    </inertial>
    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
  </link>
  <joint name="base_right_wheel" type="continuous">
    <origin xyz="-0.20 -0.245 0.05" rpy="0 0 0" />
    <parent link="raskog_basket" />
    <child link="wheel2" />
    <axis xyz="0 1 0" />
  </joint>
  <link name="raskog_basket">
    <inertial>
      <origin xyz="0 0 0" rpy="0 0 0" />
      <mass value="0.5" />
      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
    </inertial>
    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
  </link>
  <joint name="raskog_basket_joint" type="fixed">
    <origin xyz="0.00 0.17 -0.07" rpy="0 0 -1.5708" />
    <parent link="base_body" />
    <child link="raskog_basket" />
    <axis xyz="0 0 0" />
  </joint>
  <link name="raskogwheel1">
    <inertial>
      <origin xyz="0 0 0" rpy="0 0 0" />
      <mass value="0.1" />
      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
    </inertial>
    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
  </link>
  <joint name="raskogwheel1_joint" type="fixed">
    <origin xyz="0 0 0" rpy="0 0 0" />
    <parent link="raskog_basket" />
    <child link="raskogwheel1" />
    <axis xyz="0 0 0" />
  </joint>
  <link name="raskogwheel2">
    <inertial>
      <origin xyz="0 0 0" rpy="0 0 0" />
      <mass value="0.1" />
      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
    </inertial>
    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
  </link>
  <joint name="raskogwheel2_joint" type="fixed">
    <origin xyz="0 0 0" rpy="0 0 0" />
    <parent link="raskogwheel1" />
    <child link="raskogwheel2" />
    <axis xyz="0 0 0" />
  </joint>
  <link name="vertical_link">
    <inertial>
      <origin xyz="-0.000281866140488002 0.00785823838067955 0.000167237552405" rpy="0 0 0" />
      <mass value="1.13349901272872" />
      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
    </inertial>
    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
  </link>
  <joint name="vertical_lift" type="prismatic">
    <origin xyz="0 0 0.12" rpy="0 0 0" />
    <parent link="base_body" />
    <child link="vertical_link" />
    <axis xyz="0 0 1" />
    <limit lower="-0.4" upper="0.20" effort="5.0" velocity="0.0002" />
  </joint>
  <link name="left_base">
    <inertial>
      <origin xyz="-6.47167646904735E-05 0.0317790321031433 0.0165976346519832" rpy="0 0 0" />
      <mass value="0.198100409133884" />
      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
    </inertial>
    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
  </link>
  <joint name="left_base" type="fixed">
    <origin xyz="0.15726 0.026474 0.63821" rpy="-1.57 0 3.14" />
    <parent link="vertical_link" />
    <child link="left_base" />
    <axis xyz="0 0 0" />
  </joint>
  <link name="left_link1">
    <inertial>
      <origin xyz="0.000121106970690763 -0.0313187111675913 0.0119674003207884" rpy="0 0 0" />
      <mass value="0.124705001245189" />
      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
    </inertial>
    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
  </link>
  <joint name="left_arm_shoulder_pan" type="revolute">
    <origin xyz="-9.9427E-05 0.065387 0.045495" rpy="-1.5708 0 0" />
    <parent link="left_base" />
    <child link="left_link1" />
    <axis xyz="0 0 -1" />
    <limit lower="-1.996" upper="2.111" effort="20" velocity="10" />
  </joint>
  <link name="left_link2">
    <inertial>
      <origin xyz="0.019956873522225 0.0742856296056551 0.00422113879640418" rpy="0 0 0" />
      <mass value="0.159995189384934" />
      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
    </inertial>
    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
  </link>
  <joint name="left_arm_shoulder_lift" type="revolute">
    <origin xyz="-0.0172799395963306 -0.0311811002780606 0.0539361523404946" rpy="1.5708 0 0" />
    <parent link="left_link1" />
    <child link="left_link2" />
    <axis xyz="0.999994864047587 -0.00320379392081127 8.70801950002401E-05" />
    <limit lower="-2.004" upper="2.028" effort="20" velocity="10" />
  </joint>
  <link name="left_link3">
    <inertial>
      <origin xyz="0.0188635530589078 -0.0764818324673495 0.000740365189654368" rpy="0 0 0" />
      <mass value="0.135542971850972" />
      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
    </inertial>
    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
  </link>
  <joint name="left_arm_elbow_flex" type="revolute">
    <origin xyz="0.0028523 0.11238 0.028829" rpy="3.1416 0 0" />
    <parent link="left_link2" />
    <child link="left_link3" />
    <axis xyz="0.99996 -0.0032908 0.0088132" />
    <limit lower="-0.072" upper="2.995" effort="20" velocity="10" />
  </joint>
  <link name="left_link4">
    <inertial>
      <origin xyz="0.0279838202754113 -0.0363068236889853 0.000384829033235112" rpy="0 0 0" />
      <mass value="0.0742878691881685" />
      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
    </inertial>
    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
  </link>
  <joint name="left_arm_wrist_flex" type="revolute">
    <origin xyz="0.00048209729405399 -0.134148581563103 0.00362381075655138" rpy="0 0 0" />
    <parent link="left_link3" />
    <child link="left_link4" />
    <axis xyz="0.999774464019127 -0.0121028846500289 0.0174511110940406" />
    <limit lower="-2.238" upper="1.334" effort="20" velocity="10" />
  </joint>
  <link name="left_link5">
    <inertial>
      <origin xyz="8.08393796061513E-05 -0.0263409418103688 -0.00560236977442241" rpy="0 0 0" />
      <mass value="0.0992047568868334" />
      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
    </inertial>
    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
  </link>
  <joint name="left_arm_wrist_roll" type="revolute">
    <origin xyz="0.0197383915384675 -0.0617903364033804 -0.000262136225517406" rpy="0 3.14 0" />
    <parent link="left_link4" />
    <child link="left_link5" />
    <axis xyz="0.0119284594940202 0.999878198776736 0.0100647635386641" />
    <limit lower="-3.139" upper="3.140" effort="20" velocity="10" />
  </joint>
  <link name="left_link6">
    <inertial>
      <origin xyz="-0.0204038927902523 -0.00159758044103914 0.029746450173969" rpy="0 0 0" />
      <mass value="0.0208454114831758" />
      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
    </inertial>
    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
  </link>
  <joint name="left_arm_gripper" type="revolute">
    <origin xyz="0.0187720220742788 -0.0238281541937461 0.0200035092438084" rpy="1.57 0 0" />
    <parent link="left_link5" />
    <child link="left_link6" />
    <axis xyz="-0.999889727846743 0.0120164296808642 -0.00872568417324989" />
    <limit lower="0.002" upper="2.069" effort="20" velocity="10" />
  </joint>
  <link name="right_base">
    <inertial>
      <origin xyz="-6.47167852975139E-05 0.0317790320234692 0.0165976345779274" rpy="0 0 0" />
      <mass value="0.198100409607737" />
      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
    </inertial>
    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
  </link>
  <joint name="right_base" type="fixed">
    <origin xyz="-0.156575640990368 0.0302182544430658 0.638907726663402" rpy="-1.57 0 3.14" />
    <parent link="vertical_link" />
    <child link="right_base" />
    <axis xyz="0 0 0" />
  </joint>
  <link name="right_link1">
    <inertial>
      <origin xyz="0.000121106969499962 -0.0313187111595207 0.011967400309894" rpy="0 0 0" />
      <mass value="0.124705001332934" />
      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
    </inertial>
    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
  </link>
  <joint name="right_arm_shoulder_pan" type="revolute">
    <origin xyz="-9.94268621290484E-05 0.0653870978342812 0.04549462735273" rpy="-1.5708 0 0" />
    <parent link="right_base" />
    <child link="right_link1" />
    <axis xyz="0 0 -1" />
    <limit lower="-1.996" upper="2.111" effort="20" velocity="10" />
  </joint>
  <link name="right_link2">
    <inertial>
      <origin xyz="0.0199568735153524 0.0742856296207353 0.00422113879547792" rpy="0 0 0" />
      <mass value="0.159995189339826" />
      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
    </inertial>
    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
  </link>
  <joint name="right_arm_shoulder_lift" type="revolute">
    <origin xyz="-0.0172799395963307 -0.0311811002780605 0.0539361523404946" rpy="1.5708 0 0" />
    <parent link="right_link1" />
    <child link="right_link2" />
    <axis xyz="0.999994864047587 -0.00320379392081127 8.70801950002401E-05" />
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

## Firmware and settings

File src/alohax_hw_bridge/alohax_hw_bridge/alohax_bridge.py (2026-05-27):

#!/usr/bin/env python3
"""alohax_hw_bridge/alohax_bridge.py

AlohaX 统一硬件桥接节点：
  bus1 (/dev/so101_L): 左臂(ID1-6) + 驱动轮(ID7-8) + 升降(ID11)
  bus2 (/dev/so101_R): 右臂(ID1-6)

硬件变更说明：
1. 两个机械臂从肩膀上面变更为安装在肩膀下面，0位时自然下垂
2. 增加了一个升降自由度在左臂，st3215控制，id11
3. 两个驱动后轮更换到左臂控制，st3215控制，id7,8
4. 取消所有头部电机，头部相机固定

发布话题:
  /xlerobot/joint_states  (sensor_msgs/JointState) ← 整机实际状态

订阅话题：
  /joint_states                      ← joint_state_publisher_gui 滑块指令
  /xlerobot/left_arm/joint_commands  ← 左臂精细指令
  /xlerobot/right_arm/joint_commands ← 右臂精细指令
  /xlerobot/base/cmd_vel             ← 底盘 Twist 指令
"""

from __future__ import annotations

import math
import pathlib
import sys
import threading
import time
import yaml

import numpy as np
import rclpy
from rclpy.node import Node
from rclpy.action import ActionServer, CancelResponse, GoalResponse
from rclpy.executors import MultiThreadedExecutor
from rclpy.callback_groups import ReentrantCallbackGroup
from sensor_msgs.msg import JointState
from geometry_msgs.msg import Twist
from control_msgs.action import FollowJointTrajectory
from trajectory_msgs.msg import JointTrajectoryPoint

for _mod, _attr, _val in [("deepdiff", "DeepDiff", dict), ("tqdm", "tqdm", lambda it=None, **k: it or [])]:
    try:
        __import__(_mod)
    except ImportError:
        import types
        _m = types.ModuleType(_mod)
        setattr(_m, _attr, _val)
        sys.modules[_mod] = _m

from alohax_hw_bridge.motors.feetech.feetech import FeetechMotorsBus, OperatingMode
from alohax_hw_bridge.motors import Motor, MotorNormMode
from alohax_hw_bridge.motors_bus import MotorCalibration

# AlohaX 电机配置
# bus1: 左臂(ID1-6) + 驱动轮(ID7-8) + 升降(ID11)
BUS1_MOTORS = {
    "left_arm_shoulder_pan":  Motor(1, "sts3215", MotorNormMode.DEGREES),
    "left_arm_shoulder_lift": Motor(2, "sts3215", MotorNormMode.DEGREES),
    "left_arm_elbow_flex":    Motor(3, "sts3215", MotorNormMode.DEGREES),
    "left_arm_wrist_flex":    Motor(4, "sts3215", MotorNormMode.DEGREES),
    "left_arm_wrist_roll":    Motor(5, "sts3215", MotorNormMode.DEGREES),
    "left_arm_gripper":       Motor(6, "sts3215", MotorNormMode.RANGE_0_100),
    "base_left_wheel":        Motor(7, "sts3215", MotorNormMode.RANGE_M100_100),
    "base_right_wheel":       Motor(8, "sts3215", MotorNormMode.RANGE_M100_100),
    "vertical_lift":          Motor(11, "sts3215", MotorNormMode.DEGREES),  # 新增升降自由度
}

# bus2: 右臂(ID1-6)
BUS2_MOTORS = {
    "right_arm_shoulder_pan":  Motor(1, "sts3215", MotorNormMode.DEGREES),
    "right_arm_shoulder_lift": Motor(2, "sts3215", MotorNormMode.DEGREES),
    "right_arm_elbow_flex":    Motor(3, "sts3215", MotorNormMode.DEGREES),
    "right_arm_wrist_flex":    Motor(4, "sts3215", MotorNormMode.DEGREES),
    "right_arm_wrist_roll":    Motor(5, "sts3215", MotorNormMode.DEGREES),
    "right_arm_gripper":       Motor(6, "sts3215", MotorNormMode.RANGE_0_100),
}

LEFT_ARM_JOINTS  = [k for k in BUS1_MOTORS if k.startswith("left_arm")]
RIGHT_ARM_JOINTS = [k for k in BUS2_MOTORS if k.startswith("right_arm")]
BASE_WHEELS      = [k for k in BUS1_MOTORS if k.startswith("base")]
LIFT_JOINT       = "vertical_lift"
LIFT_JOINTS      = [LIFT_JOINT]
ALL_POSITION_JOINTS = LEFT_ARM_JOINTS + RIGHT_ARM_JOINTS + LIFT_JOINTS

URDF_JOINT_MAP = {k: k for k in {**BUS1_MOTORS, **BUS2_MOTORS}}

WHEEL_RADIUS  = 0.05
BASE_RADIUS   = 0.125
STEPS_PER_DEG = 4096.0 / 360.0
MAX_RAW       = 3000
RAW_POSITION_MIN = 0
RAW_POSITION_MAX = 4095
BASE_WHEEL_SIGN = {
    "base_left_wheel": -1.0,
    "base_right_wheel": 1.0,
}
LIFT_DIRECTION_SIGN = -1.0


class AlohaXBridge(Node):
    def __init__(self):
        super().__init__("alohax_bridge")

        self.declare_parameter("port1",      "/dev/so101_L")
        self.declare_parameter("port2",      "/dev/so101_R")
        self.declare_parameter("calib_file", "")
        self.declare_parameter("publish_hz", 50.0)
        self.declare_parameter("lift_travel_m", 0.25)
        self.declare_parameter("lift_motor_degrees_per_meter", 144000.0)

        port1      = self.get_parameter("port1").value
        port2      = self.get_parameter("port2").value
        calib_file = self.get_parameter("calib_file").value
        hz         = self.get_parameter("publish_hz").value
        self.lift_travel_m = float(self.get_parameter("lift_travel_m").value)
        self.lift_motor_degrees_per_meter = float(self.get_parameter("lift_motor_degrees_per_meter").value)

        self._port1 = port1
        self._port2 = port2
        self._calib_file = calib_file
        self._hz = hz
        self._ready = False
        self._active_bus1: list[str] = []
        self._active_bus2: list[str] = []

        self.bus1 = FeetechMotorsBus(port1, BUS1_MOTORS)
        self.bus2 = FeetechMotorsBus(port2, BUS2_MOTORS)

        self._write_lock = threading.Lock()
        self._traj_active = False

        self._cmd: dict[str, float] = {k: 0.0 for k in {**BUS1_MOTORS, **BUS2_MOTORS}}

        self._pub_states = self.create_publisher(JointState, "/xlerobot/joint_states", 10)
        self._pub_left_arm_state = self.create_publisher(JointState, "left_arm_state", 10)
        self._pub_right_arm_state = self.create_publisher(JointState, "right_arm_state", 10)
        self._pub_lift_state = self.create_publisher(JointState, "lift_state", 10)

        self.create_subscription(JointState, "/joint_states",
                                 self._cb_gui_cmd, 10)
        self.create_subscription(JointState, "/xlerobot/left_arm/joint_commands",
                                 self._cb_left_cmd,  10)
        self.create_subscription(JointState, "/xlerobot/right_arm/joint_commands",
                                 self._cb_right_cmd, 10)
        self.create_subscription(Twist, "/xlerobot/base/cmd_vel",
                                 self._cb_cmd_vel,   10)
        self.create_subscription(JointState, "lift_target",
                                 self._cb_lift_cmd,  10)

        self.create_timer(1.0 / hz, self._timer_cb)

        threading.Thread(target=self._connect_loop, args=(calib_file,), daemon=True).start()

        self._cb_group = ReentrantCallbackGroup()
        self._fjt_servers = {}
        for ctrl_name, joints in [
            ("both_arms_controller",   LEFT_ARM_JOINTS + RIGHT_ARM_JOINTS),
            ("left_arm_controller",    LEFT_ARM_JOINTS),
            ("right_arm_controller",   RIGHT_ARM_JOINTS),
            ("left_gripper_controller",  ["left_arm_gripper"]),
            ("right_gripper_controller", ["right_arm_gripper"]),
        ]:
            server = ActionServer(
                self,
                FollowJointTrajectory,
                f"/xlerobot/{ctrl_name}/follow_joint_trajectory",
                execute_callback=self._make_fjt_callback(joints),
                goal_callback=lambda goal_req: GoalResponse.ACCEPT,
                cancel_callback=lambda cancel_req: CancelResponse.ACCEPT,
                callback_group=self._cb_group,
            )
            self._fjt_servers[ctrl_name] = server

        self.get_logger().info(f"AlohaXBridge started @ {hz} Hz  bus1={port1}  bus2={port2} (waiting for hardware...)")

    def _connect_loop(self, calib_file: str):
        while rclpy.ok():
            try:
                self._try_connect(calib_file)
                return
            except Exception as e:
                self.get_logger().warn(f"Hardware not ready, retrying in 5s: {e}")
                time.sleep(5.0)

    def _connect_bus_partial(self, bus: FeetechMotorsBus, bus_name: str) -> list[str]:
        try:
            bus.connect(handshake=False)
        except Exception as e:
            self.get_logger().warn(f"{bus_name} connect failed: {e}")
            return []

        try:
            found = bus.broadcast_ping() or {}
        except Exception as e:
            self.get_logger().warn(f"{bus_name} ping failed: {e}")
            found = {}

        active = [name for name, motor in bus.motors.items() if motor.id in found]
        missing = [name for name in bus.motors if name not in active]

        if active:
            self.get_logger().info(
                f"{bus_name} connected on {bus.port} with active motors: {active}"
            )
        else:
            self.get_logger().warn(f"{bus_name} connected on {bus.port}, but no motors responded")

        if missing:
            self.get_logger().warn(f"{bus_name} missing motors ignored: {missing}")

        return active

    def _try_connect(self, calib_file: str):
        for bus in (self.bus1, self.bus2):
            try:
                bus.disconnect(disable_torque=False)
            except Exception:
                pass
        self.bus1 = FeetechMotorsBus(self._port1, BUS1_MOTORS)
        self.bus2 = FeetechMotorsBus(self._port2, BUS2_MOTORS)
        self._active_bus1 = self._connect_bus_partial(self.bus1, "bus1")
        self._active_bus2 = self._connect_bus_partial(self.bus2, "bus2")
        if not self._active_bus1 and not self._active_bus2:
            raise RuntimeError("No active motors found on either bus")
        self._configure_buses()
        self._load_calibration(calib_file)
        self._init_cmd_from_hardware()
        self._ready = bool(self._active_bus1 or self._active_bus2)
        self.get_logger().info("Hardware ready!")

    def _configure_buses(self):
        if self._active_bus1:
            for name in self._active_bus1:
                self.bus1.write("Return_Delay_Time", name, 0)
                self.bus1.write("Maximum_Acceleration", name, 254)
                self.bus1.write("Acceleration", name, 254)
        if self._active_bus2:
            for name in self._active_bus2:
                self.bus2.write("Return_Delay_Time", name, 0)
                self.bus2.write("Maximum_Acceleration", name, 254)
                self.bus2.write("Acceleration", name, 254)

        # bus1: 左臂+升降 - 位置模式
        for name in [n for n in LEFT_ARM_JOINTS + LIFT_JOINTS if n in self._active_bus1]:
            self.bus1.write("Operating_Mode",     name, OperatingMode.POSITION.value)
            self.bus1.write("P_Coefficient",      name, 16)
            self.bus1.write("I_Coefficient",      name, 0)
            self.bus1.write("D_Coefficient",      name, 43)
            self.bus1.write("Unloading_Condition", name, 0x2f)
        
        # bus2: 右臂 - 位置模式
        for name in [n for n in RIGHT_ARM_JOINTS if n in self._active_bus2]:
            self.bus2.write("Operating_Mode",     name, OperatingMode.POSITION.value)
            self.bus2.write("P_Coefficient",      name, 16)
            self.bus2.write("I_Coefficient",      name, 0)
            self.bus2.write("D_Coefficient",      name, 43)
            self.bus2.write("Unloading_Condition", name, 0x2f)
        
        # bus1: 驱动轮 - 速度模式
        for name in [n for n in BASE_WHEELS if n in self._active_bus1]:
            self.bus1.write("Operating_Mode", name, OperatingMode.VELOCITY.value)
            self._cmd[name] = 0.0
            self.bus1.write("Goal_Velocity", name, 0, normalize=False)
        
        if self._active_bus1:
            self.bus1.enable_torque(self._active_bus1)
        if self._active_bus2:
            self.bus2.enable_torque(self._active_bus2)

    def _load_calibration(self, calib_file: str):
        path = pathlib.Path(calib_file).expanduser() if calib_file else pathlib.Path("")
        if not path.is_file():
            self.get_logger().warn("No calibration file – running uncalibrated")
            return
        with open(path) as f:
            raw = yaml.safe_load(f)

        def to_calib(motor_obj: Motor, cfg: dict) -> MotorCalibration:
            zero_position = cfg.get("zero_position", cfg.get("home_raw"))
            return MotorCalibration(
                id=motor_obj.id,
                drive_mode=cfg.get("drive_mode", 0),
                homing_offset=cfg.get("homing_offset", 0),
                range_min=cfg.get("range_min", 0),
                range_max=cfg.get("range_max", 4095),
                zero_position=zero_position,
            )

        calib1 = {k: to_calib(BUS1_MOTORS[k], raw[k]) for k in self._active_bus1 if k in raw}
        calib2 = {k: to_calib(BUS2_MOTORS[k], raw[k]) for k in self._active_bus2 if k in raw}
        if calib1:
            self.bus1.write_calibration(calib1)
        if calib2:
            self.bus2.write_calibration(calib2)
        self.get_logger().info(f"Calibration loaded and written to motors from {path}")

    def _init_cmd_from_hardware(self):
        try:
            active_pos1 = [n for n in LEFT_ARM_JOINTS + LIFT_JOINTS if n in self._active_bus1]
            active_pos2 = [n for n in RIGHT_ARM_JOINTS if n in self._active_bus2]
            with self._write_lock:
                pos1 = self.bus1.sync_read("Present_Position", active_pos1) if active_pos1 else {}
                pos2 = self.bus2.sync_read("Present_Position", active_pos2) if active_pos2 else {}
            for k, v in {**pos1, **pos2}.items():
                self._cmd[k] = float(v)
            for k in BASE_WHEELS:
                self._cmd[k] = 0.0
            
            # 将vertical_lift强制设置为home位置（0.0米）
            # 这样RVIZ初始化时会显示在正确的home位置
            if "vertical_lift" in self._cmd:
                self._cmd["vertical_lift"] = 0.0
            
            self.get_logger().info("Initial cmd loaded from hardware")
        except Exception as e:
            self.get_logger().warn(f"Could not read initial positions: {e}")

    def _cb_gui_cmd(self, msg: JointState):
        for name, pos in zip(msg.name, msg.position):
            if name in self._cmd and name in ALL_POSITION_JOINTS:
                self._cmd[name] = self._joint_position_to_motor_degrees(name, pos)
            elif name in BASE_WHEELS:
                self._cmd[name] = float(np.clip(math.degrees(pos) / 180.0 * 100.0, -100, 100))

    def _cb_left_cmd(self, msg: JointState):
        for name, pos in zip(msg.name, msg.position):
            full = f"left_arm_{name}" if not name.startswith("left_arm") else name
            if full in self._cmd:
                self._cmd[full] = self._joint_position_to_motor_degrees(full, pos)

    def _cb_right_cmd(self, msg: JointState):
        for name, pos in zip(msg.name, msg.position):
            full = f"right_arm_{name}" if not name.startswith("right_arm") else name
            if full in self._cmd:
                self._cmd[full] = self._joint_position_to_motor_degrees(full, pos)

    def _cb_cmd_vel(self, msg: Twist):
        x     = msg.linear.x
        y     = msg.linear.y
        theta = math.degrees(msg.angular.z)
        self._cmd.update(self._body_to_wheel_pct(x, y, theta))

    def _cb_lift_cmd(self, msg: JointState):
        for name, pos in zip(msg.name, msg.position):
            full = "vertical_lift" if name == "vertical_lift" or name == "lift" else f"vertical_{name}"
            if full in self._cmd:
                self._cmd[full] = self._joint_position_to_motor_degrees(full, pos)

    def _trigger_reconnect(self):
        if self._ready:
            self._ready = False
            self.get_logger().warn("Communication lost, triggering reconnect...")
            threading.Thread(target=self._connect_loop, args=(self._calib_file,), daemon=True).start()

    def _timer_cb(self):
        if not self._ready:
            self._publish_default_joint_states()
            return
        if self._traj_active:
            return
        now = self.get_clock().now().to_msg()
        try:
            active_pos1 = [n for n in LEFT_ARM_JOINTS + LIFT_JOINTS if n in self._active_bus1]
            active_pos2 = [n for n in RIGHT_ARM_JOINTS if n in self._active_bus2]
            active_base = [n for n in BASE_WHEELS if n in self._active_bus1]
            with self._write_lock:
                pos1 = self.bus1.sync_read("Present_Position", active_pos1) if active_pos1 else {}
                pos2 = self.bus2.sync_read("Present_Position", active_pos2) if active_pos2 else {}
                vel1 = self.bus1.sync_read("Present_Velocity", active_base) if active_base else {}
        except Exception as e:
            self.get_logger().warn(f"sync_read error: {e}")
            self._trigger_reconnect()
            return

        js = JointState()
        js.header.stamp = now
        for k in LEFT_ARM_JOINTS:
            js.name.append(URDF_JOINT_MAP[k])
            js.position.append(self._motor_degrees_to_joint_position(k, float(pos1.get(k, self._cmd[k]))))
            js.velocity.append(0.0)
        for k in LIFT_JOINTS:
            js.name.append(URDF_JOINT_MAP[k])
            # vertical_lift 使用命令位置而不是硬件读取的位置
            # 这样可以确保RVIZ显示与命令一致，不受硬件初始位置影响
            js.position.append(self._motor_degrees_to_joint_position(k, float(self._cmd[k])))
            js.velocity.append(0.0)
        for k in RIGHT_ARM_JOINTS:
            js.name.append(URDF_JOINT_MAP[k])
            js.position.append(math.radians(float(pos2.get(k, self._cmd[k]))))
            js.velocity.append(0.0)
        for k in BASE_WHEELS:
            js.name.append(URDF_JOINT_MAP[k])
            js.position.append(0.0)
            js.velocity.append(float(vel1.get(k, 0.0)) * BASE_WHEEL_SIGN.get(k, 1.0))
        self._pub_states.publish(js)

        # 发布左臂状态给 teleop
        left_js = JointState()
        left_js.header.stamp = now
        for k in LEFT_ARM_JOINTS:
            left_js.name.append(URDF_JOINT_MAP[k])
            left_js.position.append(self._motor_degrees_to_joint_position(k, float(pos1.get(k, self._cmd[k]))))
        self._pub_left_arm_state.publish(left_js)

        # 发布右臂状态给 teleop
        right_js = JointState()
        right_js.header.stamp = now
        for k in RIGHT_ARM_JOINTS:
            right_js.name.append(URDF_JOINT_MAP[k])
            right_js.position.append(self._motor_degrees_to_joint_position(k, float(pos2.get(k, self._cmd[k]))))
        self._pub_right_arm_state.publish(right_js)

        # 发布升降状态给 teleop
        lift_js = JointState()
        lift_js.header.stamp = now
        for k in LIFT_JOINTS:
            lift_js.name.append(URDF_JOINT_MAP[k])
            lift_js.position.append(self._motor_degrees_to_joint_position(k, float(self._cmd[k])))
        self._pub_lift_state.publish(lift_js)

        if not self._traj_active:
            self._write_commands()

    def _publish_default_joint_states(self):
        js = JointState()
        js.header.stamp = self.get_clock().now().to_msg()
        for name in ALL_POSITION_JOINTS + BASE_WHEELS:
            js.name.append(URDF_JOINT_MAP[name])
            # vertical_lift 默认显示在home位置（0.0米）
            if name == "vertical_lift":
                js.position.append(0.0)
            else:
                js.position.append(0.0)
            js.velocity.append(0.0)
        self._pub_states.publish(js)

    def _write_commands(self):
        with self._write_lock:
            if not self._ready:
                return
            try:
                left_cmd  = {
                    k: self._clip_motor_position(k, float(self._cmd[k]))
                    for k in LEFT_ARM_JOINTS + LIFT_JOINTS
                    if k in self._active_bus1
                }
                right_cmd = {
                    k: self._clip_motor_position(k, float(self._cmd[k]))
                    for k in RIGHT_ARM_JOINTS
                    if k in self._active_bus2
                }
                wheel_cmd = {
                    k: int(round(self._cmd[k] * BASE_WHEEL_SIGN.get(k, 1.0)))
                    for k in BASE_WHEELS
                    if k in self._active_bus1
                }

                if left_cmd or right_cmd:
                    self.get_logger().debug(f"sync_write L={left_cmd}, R={right_cmd}")

                if left_cmd:
                    self.bus1.sync_write("Goal_Position", left_cmd)
                if right_cmd:
                    self.bus2.sync_write("Goal_Position", right_cmd)
                if wheel_cmd:
                    self.bus1.sync_write("Goal_Velocity", wheel_cmd, normalize=False)
            except Exception as e:
                self.get_logger().warn(f"sync_write error: {e}")

    def _clip_motor_position(self, name: str, degrees: float) -> float:
        bus = self.bus1 if name in BUS1_MOTORS else self.bus2
        motor = bus.motors.get(name)
        if motor is None:
            return float(np.clip(degrees, RAW_POSITION_MIN, RAW_POSITION_MAX))

        calibration = bus.calibration.get(name)
        if calibration is None:
            return float(np.clip(degrees, RAW_POSITION_MIN, RAW_POSITION_MAX))

        if motor.norm_mode is MotorNormMode.DEGREES:
            mid = calibration.zero_position
            if mid is None:
                mid = (calibration.range_min + calibration.range_max) / 2
            max_res = bus.model_resolution_table[motor.model] - 1
            min_degrees = (calibration.range_min - mid) * 360.0 / max_res
            max_degrees = (calibration.range_max - mid) * 360.0 / max_res
            lo, hi = sorted((min_degrees, max_degrees))
            return float(np.clip(degrees, lo, hi))

        if motor.norm_mode is MotorNormMode.RANGE_0_100:
            return float(np.clip(degrees, 0.0, 100.0))

        if motor.norm_mode is MotorNormMode.RANGE_M100_100:
            return float(np.clip(degrees, -100.0, 100.0))

        return degrees
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

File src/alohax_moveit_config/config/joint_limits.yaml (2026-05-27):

default_velocity_scaling_factor: 0.5
default_acceleration_scaling_factor: 0.5

joint_limits:
  left_arm_shoulder_pan:
    has_velocity_limits: true
    max_velocity: 10.0
    has_acceleration_limits: true
    max_acceleration: 10.0
    has_position_limits: true
    min_position: -3.14
    max_position: 3.14
  left_arm_shoulder_lift:
    has_velocity_limits: true
    max_velocity: 10.0
    has_acceleration_limits: true
    max_acceleration: 10.0
    has_position_limits: true
    min_position: -3.14
    max_position: 3.14
  left_arm_elbow_flex:
    has_velocity_limits: true
    max_velocity: 10.0
    has_acceleration_limits: true
    max_acceleration: 10.0
    has_position_limits: true
    min_position: -3.14
    max_position: 3.14
  left_arm_wrist_flex:
    has_velocity_limits: true
    max_velocity: 10.0
    has_acceleration_limits: true
    max_acceleration: 10.0
    has_position_limits: true
    min_position: -3.14
    max_position: 3.14
  left_arm_wrist_roll:
    has_velocity_limits: true
    max_velocity: 10.0
    has_acceleration_limits: true
    max_acceleration: 10.0
    has_position_limits: true
    min_position: -3.14
    max_position: 3.14
  left_arm_gripper:
    has_velocity_limits: true
    max_velocity: 10.0
    has_acceleration_limits: true
    max_acceleration: 10.0
    has_position_limits: true
    min_position: 0.0
    max_position: 1.0
  vertical_lift:
    has_velocity_limits: true
    max_velocity: 1.0
    has_acceleration_limits: true
    max_acceleration: 1.0
    has_position_limits: true
    min_position: 0.0
    max_position: 0.25
  right_arm_shoulder_pan:
    has_velocity_limits: true
    max_velocity: 10.0
    has_acceleration_limits: true
    max_acceleration: 10.0
    has_position_limits: true
    min_position: -3.14
    max_position: 3.14
  right_arm_shoulder_lift:
    has_velocity_limits: true
    max_velocity: 10.0
    has_acceleration_limits: true
    max_acceleration: 10.0
    has_position_limits: true
    min_position: -3.14
    max_position: 3.14
  right_arm_elbow_flex:
    has_velocity_limits: true
    max_velocity: 10.0
    has_acceleration_limits: true
    max_acceleration: 10.0
    has_position_limits: true
    min_position: -3.14
    max_position: 3.14
  right_arm_wrist_flex:
    has_velocity_limits: true
    max_velocity: 10.0
    has_acceleration_limits: true
    max_acceleration: 10.0
    has_position_limits: true
    min_position: -3.14
    max_position: 3.14
  right_arm_wrist_roll:
    has_velocity_limits: true
    max_velocity: 10.0
    has_acceleration_limits: true
    max_acceleration: 10.0
    has_position_limits: true
    min_position: -3.14
    max_position: 3.14
  right_arm_gripper:
    has_velocity_limits: true
    max_velocity: 10.0
    has_acceleration_limits: true
    max_acceleration: 10.0
    has_position_limits: true
    min_position: 0.0
    max_position: 1.0

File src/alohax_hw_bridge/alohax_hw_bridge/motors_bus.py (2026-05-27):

#!/usr/bin/env python

# Copyright 2024 The HuggingFace Inc. team. All rights reserved.
#
# Licensed under the Apache License, Version 2.0 (the "License");
# you may not use this file except in compliance with the License.
# You may obtain a copy of the License at
#
#     http://www.apache.org/licenses/LICENSE-2.0
#
# Unless required by applicable law or agreed to in writing, software
# distributed under the License is distributed on an "AS IS" BASIS,
# WITHOUT WARRANTIES OR CONDITIONS OF ANY KIND, either express or implied.
# See the License for the specific language governing permissions and
# limitations under the License.

# ruff: noqa: N802
# This noqa is for the Protocols classes: PortHandler, PacketHandler GroupSyncRead/Write
# TODO(aliberts): Add block noqa when feature below is available
# https://github.com/astral-sh/ruff/issues/3711

import abc
import logging
from contextlib import contextmanager
from dataclasses import dataclass
from enum import Enum
from functools import cached_property
from pprint import pformat
from typing import Protocol, TypeAlias

import serial
from deepdiff import DeepDiff
from tqdm import tqdm

# Local implementations to avoid lerobot dependency
class DeviceAlreadyConnectedError(Exception):
    pass

class DeviceNotConnectedError(Exception):
    pass

def enter_pressed():
    """Check if enter key is pressed (non-blocking)."""
    try:
        import sys, select, termios, tty
        old_settings = termios.tcgetattr(sys.stdin)
        try:
            tty.setcbreak(sys.stdin.fileno())
            if select.select([sys.stdin], [], [], 0)[0]:
                char = sys.stdin.read(1)
                return char == '\n'
        finally:
            termios.tcsetattr(sys.stdin, termios.TCSADRAIN, old_settings)
    except:
        pass
    return False

def move_cursor_up(n: int = 1):
    """Move cursor up n lines."""
    print(f"\033[{n}A", end="")

NameOrID: TypeAlias = str | int
Value: TypeAlias = int | float

logger = logging.getLogger(__name__)


def get_ctrl_table(model_ctrl_table: dict[str, dict], model: str) -> dict[str, tuple[int, int]]:
    ctrl_table = model_ctrl_table.get(model)
    if ctrl_table is None:
        raise KeyError(f"Control table for {model=} not found.")
    return ctrl_table


def get_address(model_ctrl_table: dict[str, dict], model: str, data_name: str) -> tuple[int, int]:
    ctrl_table = get_ctrl_table(model_ctrl_table, model)
    addr_bytes = ctrl_table.get(data_name)
    if addr_bytes is None:
        raise KeyError(f"Address for '{data_name}' not found in {model} control table.")
    return addr_bytes


def assert_same_address(model_ctrl_table: dict[str, dict], motor_models: list[str], data_name: str) -> None:
    all_addr = []
    all_bytes = []
    for model in motor_models:
        addr, bytes = get_address(model_ctrl_table, model, data_name)
        all_addr.append(addr)
        all_bytes.append(bytes)

    if len(set(all_addr)) != 1:
        raise NotImplementedError(
            f"At least two motor models use a different address for `data_name`='{data_name}'"
            f"({list(zip(motor_models, all_addr, strict=False))})."
        )

    if len(set(all_bytes)) != 1:
        raise NotImplementedError(
            f"At least two motor models use a different bytes representation for `data_name`='{data_name}'"
            f"({list(zip(motor_models, all_bytes, strict=False))})."
        )


class MotorNormMode(str, Enum):
    RANGE_0_100 = "range_0_100"
    RANGE_M100_100 = "range_m100_100"
    DEGREES = "degrees"


@dataclass
class MotorCalibration:
    id: int
    drive_mode: int
    homing_offset: int
    range_min: int
    range_max: int
    zero_position: int | None = None


@dataclass
class Motor:
    id: int
    model: str
    norm_mode: MotorNormMode


class JointOutOfRangeError(Exception):
    def __init__(self, message="Joint is out of range"):
        self.message = message
        super().__init__(self.message)


class PortHandler(Protocol):
    def __init__(self, port_name):
        self.is_open: bool
        self.baudrate: int
        self.packet_start_time: float
        self.packet_timeout: float
        self.tx_time_per_byte: float
        self.is_using: bool
        self.port_name: str
        self.ser: serial.Serial

    def openPort(self): ...
    def closePort(self): ...
    def clearPort(self): ...
    def setPortName(self, port_name): ...
    def getPortName(self): ...
    def setBaudRate(self, baudrate): ...
    def getBaudRate(self): ...
    def getBytesAvailable(self): ...
    def readPort(self, length): ...
    def writePort(self, packet): ...
    def setPacketTimeout(self, packet_length): ...
    def setPacketTimeoutMillis(self, msec): ...
    def isPacketTimeout(self): ...
    def getCurrentTime(self): ...
    def getTimeSinceStart(self): ...
    def setupPort(self, cflag_baud): ...
    def getCFlagBaud(self, baudrate): ...


class PacketHandler(Protocol):
    def getTxRxResult(self, result): ...
    def getRxPacketError(self, error): ...
    def txPacket(self, port, txpacket): ...
    def rxPacket(self, port): ...
    def txRxPacket(self, port, txpacket): ...
    def ping(self, port, id): ...
    def action(self, port, id): ...
    def readTx(self, port, id, address, length): ...
    def readRx(self, port, id, length): ...
    def readTxRx(self, port, id, address, length): ...
    def read1ByteTx(self, port, id, address): ...
    def read1ByteRx(self, port, id): ...
    def read1ByteTxRx(self, port, id, address): ...
    def read2ByteTx(self, port, id, address): ...
    def read2ByteRx(self, port, id): ...
    def read2ByteTxRx(self, port, id, address): ...
    def read4ByteTx(self, port, id, address): ...
    def read4ByteRx(self, port, id): ...
    def read4ByteTxRx(self, port, id, address): ...
    def writeTxOnly(self, port, id, address, length, data): ...
    def writeTxRx(self, port, id, address, length, data): ...
    def write1ByteTxOnly(self, port, id, address, data): ...
    def write1ByteTxRx(self, port, id, address, data): ...
    def write2ByteTxOnly(self, port, id, address, data): ...
    def write2ByteTxRx(self, port, id, address, data): ...
    def write4ByteTxOnly(self, port, id, address, data): ...
    def write4ByteTxRx(self, port, id, address, data): ...
    def regWriteTxOnly(self, port, id, address, length, data): ...
    def regWriteTxRx(self, port, id, address, length, data): ...
    def syncReadTx(self, port, start_address, data_length, param, param_length): ...
    def syncWriteTxOnly(self, port, start_address, data_length, param, param_length): ...
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
